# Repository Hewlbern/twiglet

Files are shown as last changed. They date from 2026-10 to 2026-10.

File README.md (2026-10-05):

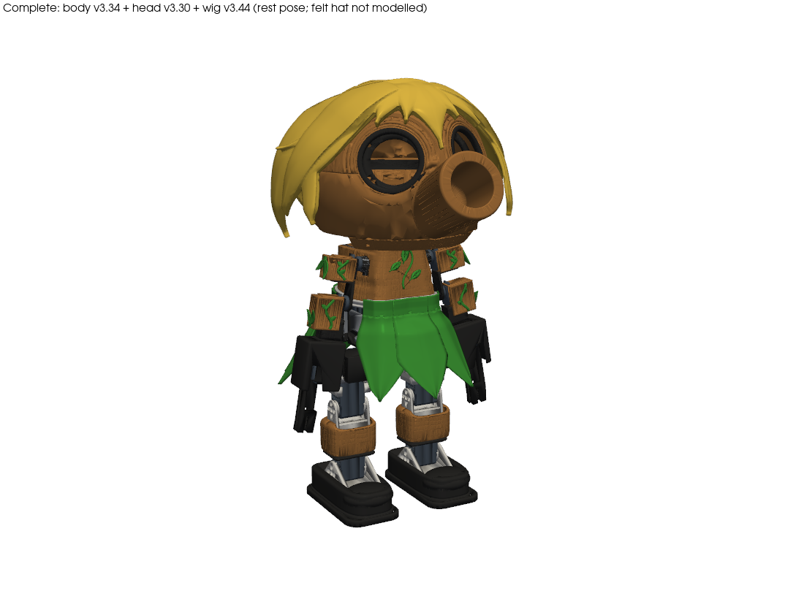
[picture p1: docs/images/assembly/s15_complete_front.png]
Twiglet: complete robot, rest pose (render)


# Twiglet

**Twiglet** is a ~50 cm, 19-DoF 3D-printed biped with a wooden-ball head, two round digital eyes, a printed hair piece under a felt hat, a leaf kilt and two small arms with grippers. It is **inspired by** [Open Duck Mini](https://github.com/apirrone/Open_Duck_Mini/tree/v2) (v2), and reuses some of its open-source parts (legs, neck, electronics) under Apache-2.0 — see [NOTICE](NOTICE).

[Hardware →](#hardware) · [BOM →](docs/BOM.md) · [Print →](docs/print_guide.md) · [Assemble →](docs/assembly_guide.md) · [Simulation →](experiments/README.md) · [Contribute →](CONTRIBUTING.md)

> **Status: simulation only.** Nothing has been printed or built yet, so every number below is from MuJoCo and mesh checks. Photos and videos of a real build are TODO.

| | | |
|:-:|:-:|:-:|
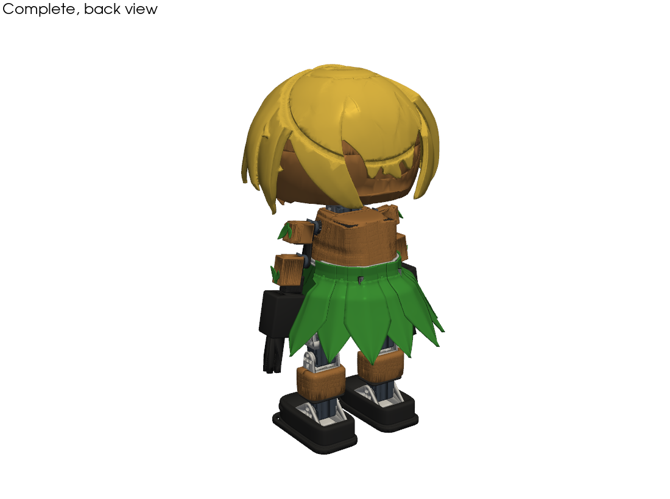
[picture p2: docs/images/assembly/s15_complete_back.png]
complete, back
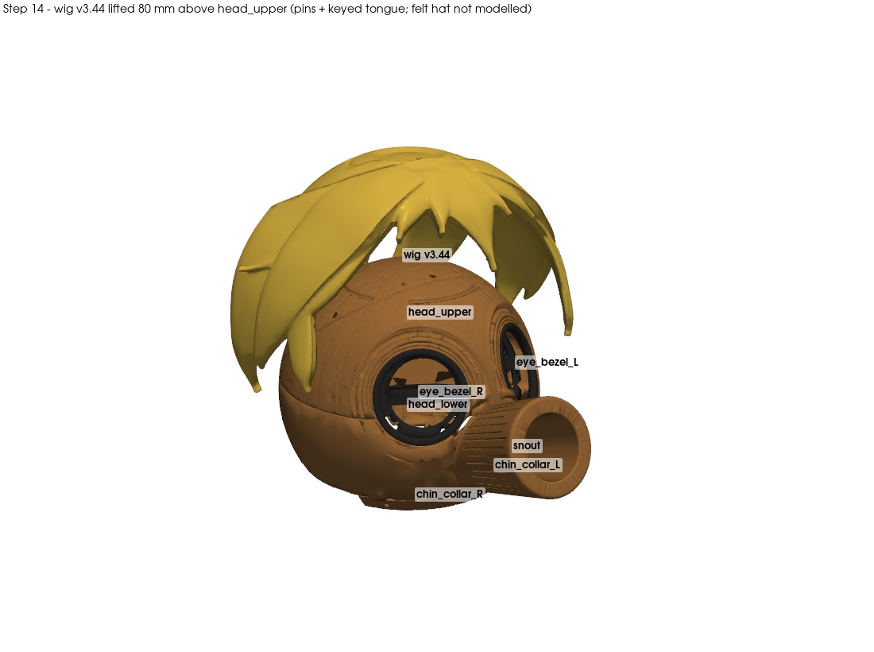
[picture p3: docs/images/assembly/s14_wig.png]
wig on the head
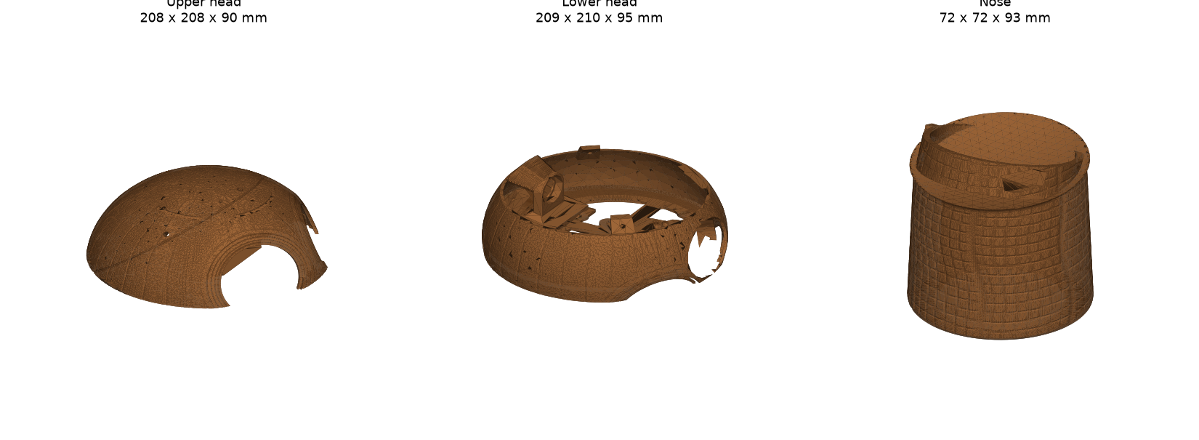
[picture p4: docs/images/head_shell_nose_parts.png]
head shells and nose
|  |  |  |
| **Complete, back view** | **Head + hair piece v3.44** | **Head shells and nose** |
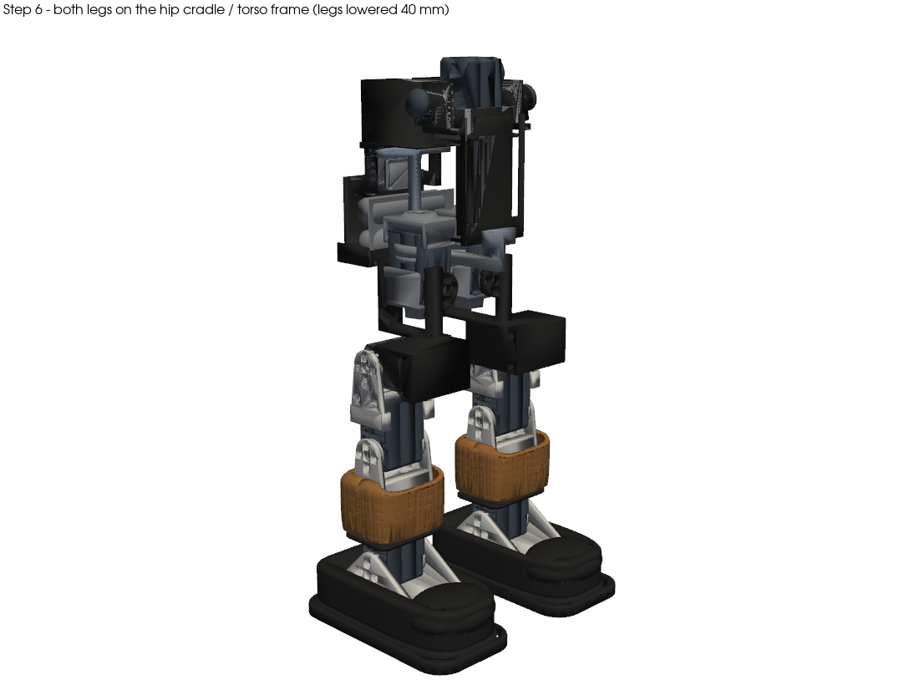
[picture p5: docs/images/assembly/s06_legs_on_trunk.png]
legs on the trunk
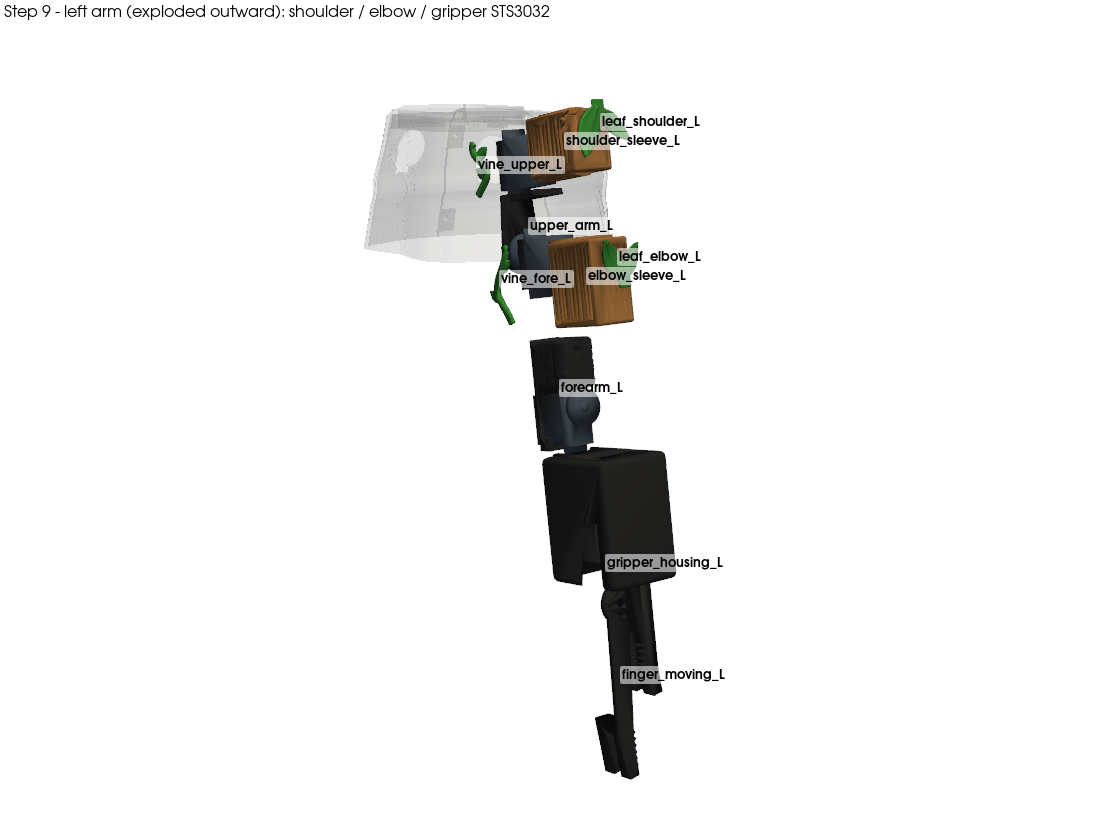
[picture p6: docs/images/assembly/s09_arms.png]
arms
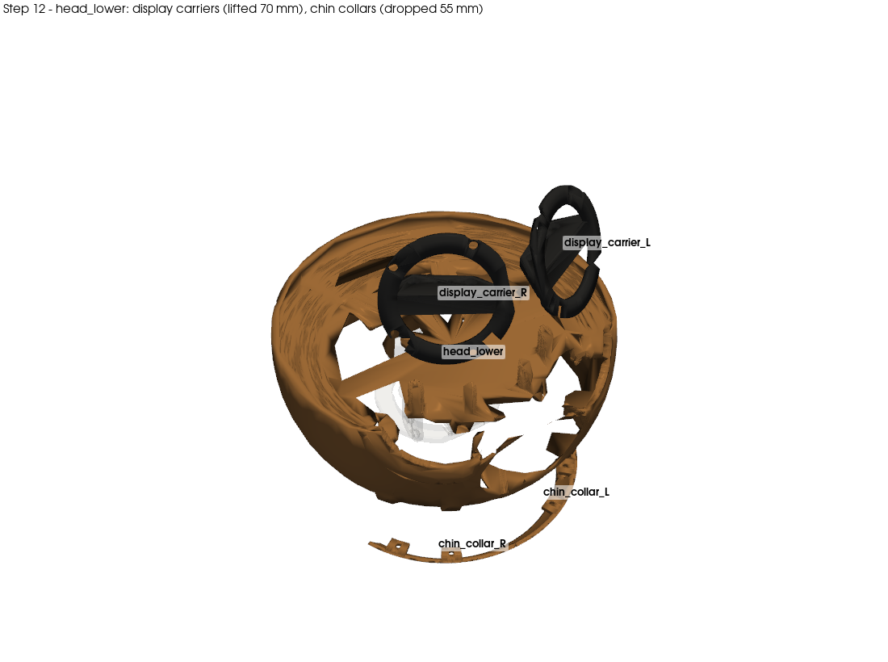
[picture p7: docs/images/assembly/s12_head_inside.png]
head inside
|  |  |  |
| **Legs on the trunk** | **3-DoF arms (STS3032)** | **Head inside: Pi, eyes, ballast** |

## Highlights

- **Head:** a new wood-textured ball head (v3.30) with a hollow nose and two 2.1" round touch LCDs as eyes (ESP32-S3; firmware in [`experiments/twiglet_eyes/`](experiments/twiglet_eyes/README.md)), using a 3-servo neck (Open Duck Mini v2-compatible).
- **Hair piece:** one printed piece (v3.44, 186 g at 4.5 % infill) that pins and keys onto the head; a felt hat goes over it.
- **Body:** a slim torso cone with a 10-petal leaf kilt, shin covers and boots (body v3.34, 50 STLs).
- **Arms:** two 3-DoF arms (shoulder, elbow, gripper) on Feetech STS3032 micro bus servos, powered from a 6 V buck regulator.
- **Simulation and checks:** MuJoCo model, open-loop gait parameters, standing, push and neck-load tests, plus collision and print-file checks on the real meshes. All of it runs from this repo.

## Hardware

| Category | Item | Specification |
|---|---|---|
| Body | Size | about 340 × 276 × 499 mm (feet to hair top, rest pose; hat not modelled) |
| Body | Mass (sim model) | 2.753 kg; head 0.814 kg including the 25 g ballast and the hair piece |
| Motion | Joints | 19: 10 legs + 3 neck (13 × Feetech STS3215), 6 arms (Feetech STS3032) |
| Computing | Main board | Raspberry Pi Zero 2W (as upstream) |
| Sensing | IMU | BNO055 (as upstream) |
| Interaction | Eyes | 2 × Waveshare ESP32-S3-Touch-LCD-2.1 (480 × 480 round), UART from the Pi |
| Power | Battery | 2S 18650 (2 cells) + 2S BMS; 5 V UBEC for logic and eyes; 6 V buck for the arm servos |
| Printing | Printer used for the checks | Bambu P1S (every part fits 256 × 256 × 256 mm), PLA / PETG / optional TPU |

Full parts list with links and prices: [docs/BOM.md](docs/BOM.md) (CSV: [docs/BOM.csv](docs/BOM.csv)). Several prices are still TODO.

## Simulation results

From [`experiments/`](experiments/README.md), model `experiments/twiglet_sim/models/twiglet_v3_v334_wig344.xml` (body v3.34 + head v3.30 + hair v3.44), re-run from this repo on 5 Oct 2026:

| check | result | pass criterion |
|---|---|---|
| standing margin (crouch 0.10) | 50.5 mm | no fall, > 30 mm |
| head + arm motion (e-margin) | 34.1 mm | ≥ 30 mm |
| neck-pitch static hold | 0.232 N·m = **2.11×** the STS3215 rating | ≥ 2× |
| main gait, 20 randomized trials | **19/20** at 0.206 m/s | ≥ 19/20 |
| main gait, 20 held-out seeds | 18/20 at 0.206 m/s | ≥ 18/20 |
| efficient gait, 20 randomized trials | **20/20** at 0.156 m/s | ≥ 19/20 |
| hair vs arms inside the soft limits | 0 / 0 / 0 (yaw 0 / −45 / +45) | 0 |
| 315-pose head range | 154/315 poses with any contact, 0 hair-only | ≤ ~154, 0 hair-only |
| eye coverage by the hair | 0 / 0 triangles | 0 |
| print files | watertight, 1 body, fit the P1S | all |

The gaits are 12-parameter open-loop/PD vectors ([BEST_WALK_PARAMS_v334r1.npy](BEST_WALK_PARAMS_v334r1.npy), [BEST_WALK_EFF_PARAMS_v333r1.npy](BEST_WALK_EFF_PARAMS_v333r1.npy); see `experiments/twiglet_sim/walk_search.py`), **not** ONNX RL policies like upstream's. Training a policy with [Open_Duck_Playground](https://github.com/apirrone/Open_Duck_Playground) is TODO.

## Where to find things

| Resource | Purpose |
|---|---|
| [docs/BOM.md](docs/BOM.md) | Parts list (upstream columns + our extra parts) |
| [docs/print_guide.md](docs/print_guide.md) | Which stock parts are still used, plus the print settings of every new part (some are **required**: the sims assume them) |
| [docs/assembly_guide.md](docs/assembly_guide.md) | 15-step build with rendered step images |
| [print/mods/Twiglet/](print/mods/Twiglet/README.md) | New STLs (print-oriented), Blender sources and build scripts |
| [mini_bdx/robots/twiglet_v334/](mini_bdx/robots/twiglet_v334/README.md) | MuJoCo model (MJCF + meshes) |
| [experiments/](experiments/README.md) | Every simulation and geometry check, how to run it, and the reference results |
| [docs/configure_motors.md](docs/configure_motors.md), [docs/sim2real.md](docs/sim2real.md), [docs/prepare_robot.md](docs/prepare_robot.md) | Servo IDs, sim-to-real notes, how the model was made |
| [docs/upstream/](docs/upstream/) | The upstream Open Duck Mini v2 docs, unchanged, for reference |

For the stock Open Duck Mini v2 parts use upstream's [Onshape CAD](https://cad.onshape.com/documents/64074dfcfa379b37d8a47762/w/3650ab4221e215a4f65eb7fe/e/0505c262d882183a25049d05) and [BOM](https://docs.google.com/spreadsheets/d/1gq4iWWHEJVgAA_eemkTEsshXqrYlFxXAPwO515KpCJc/edit?usp=sharing). The onboard runtime is upstream's [Open_Duck_Mini_Runtime](https://github.com/apirrone/Open_Duck_Mini_Runtime) (TODO: add the arm servos and the eye UART).

### Large files

Every file is under GitHub's 100 MB limit. Over 25 MB: `print/mods/Twiglet/source/blender/body_v334.blend` (59 MB). The head v3.30 `.blend` (194 MB) is not included; its rebuild scripts are in `print/mods/Twiglet/source/scripts/head_v3.30/`.

## Credits

Twiglet is **inspired by** **[Open Duck Mini](https://github.com/apirrone/Open_Duck_Mini)** (v2) by Antoine Pirrone ([apirrone](https://github.com/apirrone)) and the Open Duck Mini contributors (see [thanks.md](thanks.md)), sponsored by HuggingFace and Pollen Robotics. Some stock Open Duck Mini v2 parts, wiring diagrams and docs are reused here under the Apache License 2.0; [NOTICE](NOTICE) lists exactly which files are theirs, unmodified or modified. Thanks also to Rhoban for [BAM](https://github.com/Rhoban/bam), and to the [MuJoCo](https://github.com/google-deepmind/mujoco), [trimesh](https://github.com/mikedh/trimesh), [PyVista](https://github.com/pyvista/pyvista) and [Blender](https://www.blender.org/) projects.

This project is not affiliated with or endorsed by Pollen Robotics, HuggingFace or the Open Duck Mini project.

## License

Copyright 2026 Mike Holborn (DreamMachina).

The new material in this repository is licensed under the [Apache License 2.0](LICENSE). The Open Duck Mini v2 material stays under its own Apache-2.0 terms and copyright; see [NOTICE](NOTICE). Contributions are accepted under the same licence (see [CONTRIBUTING.md](CONTRIBUTING.md)).

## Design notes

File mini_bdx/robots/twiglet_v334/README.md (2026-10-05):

# twiglet_v334

This is the MuJoCo model of the Twiglet robot (body v3.34, head v3.30). Layout follows the Open Duck Mini v2 robot folder convention.

- `twiglet_v3.xml`: the MJCF, with 19 position actuators:
  - left/right `hip_yaw`, `hip_roll`, `hip_pitch`, `knee`, `ankle`
  - `head_pitch`, `head_yaw`, `head_roll`
  - `shoulder_L/R`, `elbow_L/R`, `gripper_L/R`
- `twiglet_v3_wig344.xml`: **the current robot**, the same model with the head inertial of the wig v3.44 (hair c14) head: 2.753 kg total, head 0.814 kg. It is a copy of `experiments/twiglet_sim/models/twiglet_v3_v334_wig344.xml` (made by `experiments/twiglet_sim/tools/make_v334_wig.py`).
- Total mass of `twiglet_v3.xml`: 2.753 kg.
- `meshes/`: 60 STL visual meshes. Contact is only the floor vs 4 boxes (trunk, feet, head); part-to-part clearance is checked on the print meshes in `experiments/twiglet_geom/`.
- `mass_v334.json`: the per-part mass deltas applied for v3.34.
- There is no URDF or onshape-to-robot `config.json`: the model was not made from Onshape (TODO, if the runtime/playground needs them).
- The 25 g head ballast is included in both. `twiglet_v3.xml` has the older v3.30-era fringe in the head mass; `twiglet_v3_wig344.xml` has wig v3.44.
- All the other versions (body v3.20–v3.34, infill sweeps, hair series) are in `experiments/twiglet_sim/models/`.

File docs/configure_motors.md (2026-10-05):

# Configure the motors

> This is based on the [Open Duck Mini v2 guide](https://github.com/apirrone/Open_Duck_Mini/blob/v2/docs/configure_motors.md). A verbatim copy is in [upstream/configure_motors.md](upstream/configure_motors.md).

> This sould be done independently on each motor *before* builiding the duck.
>
> During the process, the motor will move to its zero position. You can then install the horn while trying to align it the best you can. (Don't worry if it's not perfect, we will compensate for that later)

Clone and install (`pip install -e .`) the runtime repo on the `v2` branch : `https://github.com/apirrone/Open_Duck_Mini_Runtime`

Then for each motor, run the following command : 

```bash
python configure_motor.py --id <id>
```

The STS3215 IDs are upstream's, minus `neck_pitch`: Twiglet has had no neck-pitch servo since v3.5, so there are 13 STS3215s.

```python
{
    "left_hip_yaw": 20,
    "left_hip_roll": 21,
    "left_hip_pitch": 22,
    "left_knee": 23,
    "left_ankle": 24,
    # "neck_pitch": 30,  # not used in twiglet
    "head_pitch": 31,
    "head_yaw": 32,
    "head_roll": 33,
    "right_hip_yaw": 10,
    "right_hip_roll": 11,
    "right_hip_pitch": 12,
    "right_knee": 13,
    "right_ankle": 14,
}
```

The arm servos are 6× Feetech **STS3032**. They use the same STS TTL protocol and bus, but have to be powered from the **6 V** branch, not straight from the 2S pack.

```python
{
    # TODO: arm servo IDs not decided. The joint names below are the ones in the sim model.
    "shoulder_L": None,
    "elbow_L": None,
    "gripper_L": None,
    "shoulder_R": None,
    "elbow_R": None,
    "gripper_R": None,
}
```

- TODO: check that `configure_motor.py` works on the STS3032. The protocol and register map are said to be the same as the STS3215, but this has not been tested.

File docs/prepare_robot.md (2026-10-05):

# Prepare the robot (from design to MuJoCo)

> Upstream's version goes from the Onshape design to MuJoCo through onshape-to-robot: see [upstream/prepare_robot.md](upstream/prepare_robot.md). Twiglet has no Onshape document, so its model was made differently.

## Our model

- **Model file:** `mini_bdx/robots/twiglet_v334/twiglet_v3.xml`, with its meshes in `meshes/`.
  - 19 actuators: 10 legs, head_pitch/yaw/roll, and shoulder/elbow/gripper L/R.
  - 2.753 kg in total.
- **Current robot with wig v3.44:** `twiglet_v3_wig344.xml` (2.753 kg, head 0.814 kg), made by `experiments/twiglet_sim/tools/make_v334_wig.py`: the v3.34 model with the head inertial and head collision box of the hair c14 (v3.44) model `hair_c14_v344.xml`. That script runs from the repo (it only reads three files in `models/`). The 52 versions and variants are in `experiments/twiglet_sim/models/`.
- **How it was built:**
  - `experiments/twiglet_sim/tools/gen_mjcf_v3.py` built the v3 MJCF from the Open Duck Mini v2 kinematics, using the mass rules of our earlier body-v2 model plus new part kinds (STS3032 cases, light-print head, displays).
  - Each later version edited it. For example, `experiments/twiglet_sim/tools/mass_v334.py` adds the changed-part mass deltas (solid PLA, 1.24 g/cm3) to the bodies they ride on.
  - The mass bookkeeping is in `mini_bdx/robots/twiglet_v334/mass_v334.json`.
- **Reference only:** `gen_mjcf_v3.py`, `mass_v334.py` and `make_xml_variant.py` read caches and earlier versions from the original build workspace. They don't run on their own from this repo (TODO: make them self-contained).
- **Mass assumptions:** the head is modelled at 2 walls + 8 % infill (wig 4.5 % lightning), with the head shells, snout and chin collars in PETG at 1.27 g/cm3 and 25 g of rear ballast. Print exactly that, or the model no longer matches.
- **STS3032 arm actuators:**
  - ctrlrange is clipped to ±0.441 N·m (stall at 6 V).
  - The armature (0.004) is an estimate. The STS3032 has not been identified with BAM (TODO).

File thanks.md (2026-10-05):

Twiglet is inspired by Open Duck Mini by Antoine Pirrone ([apirrone](https://github.com/apirrone)): https://github.com/apirrone/Open_Duck_Mini. Thank you!

People involved in the original Open Duck Mini project, as listed in upstream's `thanks.md`:

- Mimir Reynisson
- Grégoire Passault
- Augustin Crampette
- Michel Aractingi
- Mankaran Singh
- Steve N'Guyen
- Pierre Rouanet
- Thomas Wolf

Also thanks to HuggingFace and Pollen Robotics for sponsoring Open Duck Mini, to Rhoban for [BAM](https://github.com/Rhoban/bam), and to Waveshare for the ESP32-S3-Touch-LCD-2.1 demo code the eye firmware is ported from.

Twiglet: DreamMachina / Mike Holborn.

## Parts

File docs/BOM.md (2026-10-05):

# BOM

> This uses the same columns and sections as the [upstream Open Duck Mini v2 BOM](https://docs.google.com/spreadsheets/d/1gq4iWWHEJVgAA_eemkTEsshXqrYlFxXAPwO515KpCJc/edit?usp=sharing).
> - Lines marked [upstream line] are upstream's, with their links and € prices. Only the amounts are changed for twiglet.
> - Prices we don't know are TODO.
> - CSV version: [BOM.csv](BOM.csv). Printed parts: see [print_guide.md](print_guide.md).

| section | Part | link | amount | unit price (€) | total price (€) | Estimated lowest price (€) | Comment |
|---|---|---|---|---|---|---|---|
| Power | 18650 cell | [link](https://www.nkon.nl/fr/molicel-inr18650-p30b-3000mah-30a.html) | 2 | 5 | 10 | 10 | Get the beefiest 18650 cells you can find. I have 3000mAh with 30A discharge [upstream line] |
|  | 18650 cell holder | [link](https://www.amazon.fr/CABLEPELADO-Support-pour-piles-MR18650/dp/B08YDTSML8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) | 1 | 4,99 | 4,99 | 4,99 | [upstream line] |
|  | 2S BMS | [link](https://shorturl.at/OEXM1) | 1 | 8,4 | 8,4 | 8,4 | [upstream line] |
|  | 5V regulator | [link](https://www.alibaba.com/product-detail/HENGE-4A-6A-8A-12A-UBEC_1601260325461.html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) | 1 | 4 | 4 | 4 | Also feeds the 2 eye boards (budget +0.5 A, not measured). TODO: check the headroom [upstream line] |
|  | Small power switch | [link](https://www.amazon.fr/dp/B0CH3JCQM5?psc=1&ref=ppx_yo2ov_dt_b_product_details) | 1 | 4,49 | 4,49 | 4,49 | Need only one [upstream line] |
|  | usb-c charger | [link](https://www.amazon.fr/dp/B0BWTK7SVN?psc=1&ref=ppx_yo2ov_dt_b_product_details) | 1 | 9,99 | 9,99 | 9,99 | need only one [upstream line] |
|  | 2.1mm barrel jack | [link](https://www.amazon.fr/AERZETIX-connecteur-Adaptateur-dalimentation-souder/dp/B07VQ6VFDN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) | 2 | 1 | 2 | 2 | Need only two [upstream line] |
|  | XT15? XT30 ? | [link](https://www.amazon.fr/RUNCCI-connecteur-XT30Connecteurs-Batterie-connecteurs/dp/B07PC1YKVW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) | 1 | 8 | 8 | 0.5 | You only need one pair (male/female) but hard to buy just one. Estimated lowest price is the price of 1, unit price is the price of a bundle [upstream line] |
|  | 6V buck regulator for the arm branch (e.g. Pololu D36V50F6, 6V 5.5A) |  | 1 | TODO | TODO | TODO | Twiglet: the STS3032 max is 7.4V and a full 2S is 8.4V. TODO: link and price |
| Servos, control and sensors | IMU (BNO055) | [link](https://www.amazon.fr/gp/product/B017PEIGIG/ref=ox_sc_act_title_2?smid=AZ997SEAZ4L8C&psc=1) | 1 | 40 | 40 | 1 | Need to find a cheaper alternative. Saw ~1$ ones on ali, but would have to try them https://www.alibaba.com/product-detail/BNO055-9DOF-9-axis-Absolute-Orientation_1601030871509.html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 [upstream line] |
|  | Raspberry pi zero 2w | [link](https://t.ly/M21v4) | 1 | 26,08 | 26,08 | 26,08 | [upstream line] |
|  | SD card | [link](https://www.amazon.fr/SanDisk-M%C3%A9moire-microSDHC-Adaptateur-homologu%C3%A9e/dp/B08GY9NYRM/257-3914705-5327951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) | 1 | 10 | 10 | 10 | TODO can find cheaper [upstream line] |
|  | Servo control board | [link](https://www.waveshare.com/bus-servo-adapter-a.htm) | 1 | 5 | 5 | 5 | [upstream line] |
|  | Feetech 7.4v STS 3215 | [link](https://www.alibaba.com/product-detail/Robot-Servo-STS3215-7-4V-19kg_1600052037414.html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) | 13 | 14 | 182 | TODO | 13, not 14: 10 legs + head pitch/yaw/roll (the neck-pitch servo was removed in v3.5). Be sure to buy the 7.4v ones [upstream line] |
|  | Feetech STS3032 (C001) micro bus servo | [link](https://shop.babsco.com/feetech-sts3032-4-5kg-compact-smart-servo-c001) | 6 | TODO (US$32.99) | TODO (US$197.94) | TODO | Twiglet arms: shoulder, elbow and gripper per side. Prices seen: US$32.99 BABSCO; EUR 37.20 Eckstein |
|  | Feet contact switches (SS-10) | [link](https://fr.aliexpress.com/item/1005006164610609.html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) | TODO | 1 | TODO | TODO | TODO: fitted or not? They are not modelled in the sim [upstream line] |
|  | 9g servos | [link](https://www.amazon.fr/Miuzei-H%C3%A9licopt%C3%A8re-V%C3%A9hicules-Contr%C3%B4le-Mod%C3%A9lisme/dp/B0BBR4D8SZ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) | 0 | 3,33 | 0 | TODO | Not used: the antennas are omitted [upstream line] |
|  | Waveshare ESP32-S3-Touch-LCD-2.1 (flat, SKU 28169) | [link](https://www.waveshare.com/esp32-s3-touch-lcd-2.1.htm?sku=28169) | 2 | TODO (US$32.99) | TODO (US$66) | TODO | Twiglet digital eyes. Do NOT buy the 2.1B (curved glass). In AU: about AU$126 for 2 (Zaitronics) |
|  | SH1.0 12-pin cable, ~150 mm |  | 2 | TODO | TODO (~AU$5) | TODO | For the eyes. Check the display box first |
|  | 4-pin inline connector + ~30 cm of 26 AWG wire |  | 1 | TODO | TODO (~AU$3) | TODO | Eyes to Pi |
| MISC | 3D printing M3 inserts | [link](https://www.amazon.fr/dp/B09ZPF48VK?psc=1&ref=ppx_yo2ov_dt_b_product_details) | 1 | 5,99 | 5,99 | 5,99 | Twiglet extras: 4x M3x5x4 (chin collars), 4x M3x4x5 (display carriers) and 4 (head halves). Total count TODO [upstream line] |
|  | M3x8 socket-head screws |  | 8 | TODO | TODO | TODO | 4 for the chin collars + 4 for the display carriers |
|  | M3 screws, head-half joint |  | 4 | TODO | TODO | TODO | Length TODO |
|  | M3 screws (other) |  | TODO | TODO | TODO | TODO | Upstream says "X m3 screws (TODO)". The Twiglet body/arm fasteners are TODO too |
|  | M2x5 pan/button-head screws |  | 8 | TODO | TODO (<AU$3) | TODO | Displays to carriers |
|  | M2 screws, arms |  | TODO | TODO | TODO | TODO | upper_arm to the sleeve and servo ears (from the v3.1/v3.8 notes). Count and length TODO |
|  | Standard PLA |  | 1 | 20 | 20 | 0 | Twiglet colours: black, wood-brown, green, yellow/blond. Amount TODO [upstream line] |
|  | PETG, wood-brown |  | TODO | TODO | TODO | TODO | Head shells, snout and chin collars |
|  | TPU |  | 1 | 0 | 0 | 0 | (for the feet, negligeable cost). Optional TPU 95A for the kilt petals, leaves and boots [upstream line] |
|  | Cable sheath | [link](https://www.amazon.fr/gp/product/B07PGMKC3T/ref=ox_sc_act_title_4?smid=A33G7CY43FZYTX&psc=1) | 1 | 9 | 9 | 9 | [upstream line] |
|  | 15cm micro usb to usb-c cable | [link](https://www.amazon.fr/AmazonBasics-C%C3%A2ble-USB-C-vers-Micro/dp/B01LONQ7R6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) | 1 | 7 | 7 | 7 | [upstream line] |
|  | 50cm micro usb to usb c cable | [link](https://www.amazon.fr/gp/product/B0BFWSP4PP/ref=ox_sc_act_title_2?smid=A1VSNBJQRMXLRM&psc=1) | 1 | 6 | 6 | 6 | [upstream line] |
|  | Bearing | [link](https://www.amazon.fr/dp/B0CXXSVFTV?ref=ppx_yo2ov_dt_b_fed_asin_title) | 3 | 3,5 | 10,5 | 10,5 | The head roll bearing is 20x32x7 (in head_lower). TODO: confirm whether the other 2 (trunk) are still needed [upstream line] |
|  | Steel ballast, 25 g (e.g. 5x M8 hex nuts) |  | 1 | TODO | TODO | TODO | Required. Epoxied inside the back of head_lower; must weigh 23-27 g |
|  | 3 mm steel rod (or PLA filament), cut to 12 mm |  | 4 | TODO | TODO | TODO | Wig pins |
|  | 2-part epoxy + medium CA |  | 1 | TODO | TODO | TODO | For the wig, snout, ballast and leaves |
|  | Loctite 243 |  | 1 | TODO | TODO | TODO | From the upstream assembly guide |
|  | Felt hat (fabric) |  | 1 | TODO | TODO | TODO | Not printed |
|  | 0.3-0.5 mm black foam tape ring (optional) |  | 2 | TODO | TODO | TODO | Between the bezel and the glass |
| "Expression package" | (upstream projector, speaker, LEDs, microphone, eye diffusers, amplifier, camera) | [link](https://docs.google.com/spreadsheets/d/1gq4iWWHEJVgAA_eemkTEsshXqrYlFxXAPwO515KpCJc/edit?usp=sharing) | 0 |  |  |  | Replaced by the digital eyes. TODO: decide on the speaker, amplifier and camera |
|  |  |  |  | Total | TODO | TODO | Not totalled: several prices are TODO |

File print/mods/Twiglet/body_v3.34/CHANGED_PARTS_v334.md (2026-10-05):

# Twiglet body v3.34: changed-part list (compared with v3.33)

Every part not listed is the same file as in v3.33 (the v333_ arm files are copied unchanged from the v3.33 zip; the v3.34 rebuild gave identical volumes and extents).

| Part | v3.34 file | Replaces | What changed | Solid vol v3.33 -> v3.34 |
|---|---|---|---|---|
| gripper_housing_L/R | v334_gripper_housing_L/R.stl | v333_gripper_housing_L/R | FEETECH box enlarged to 36.4 x 47.3 x 57.0 mm (was 29.4 x 47.3 x 43.0): +14 mm along the forearm (down), +3.5 mm depth per side. Still a hollow 1.6 mm shell with an open bottom; servo seat, prongs and finger unchanged (seat overlap 214.6 mm3 = rev C). | 37.01 -> 41.72 cm3 |
| kilt_petal_00..02 (front) | v334_kilt_petal_00..02.stl | v333_kilt_petal_00..02 | Flare radius 98 -> 118 mm about the kilt axis; hem height unchanged (-66); side edges clamp at |y| 65.5 (arm corridor). Pointed tips kept. | 8.28/8.50/8.28 -> 9.07/9.78/9.07 cm3 |
| kilt_petal_03..09 (sides/back) | v334_kilt_petal_03..09.stl | v333_kilt_petal_03..09 | Flare radius 102 -> 122 mm, hem 6 mm lower (-72); the side-back petals now reach |y| 124.6 behind the arms. | 6.26-7.89 -> 7.64-9.30 cm3 |

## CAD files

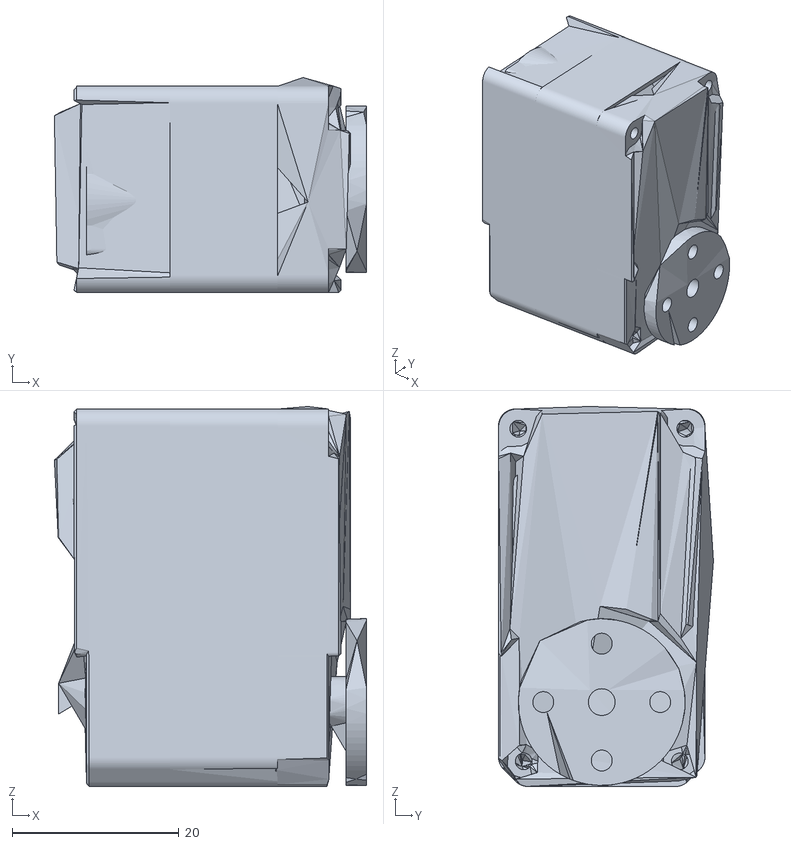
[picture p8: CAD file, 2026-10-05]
mini_bdx/robots/twiglet_v334/meshes/v3_hip_roll_assembly_2_servo.stl
37.4 x 25.7 x 45.5

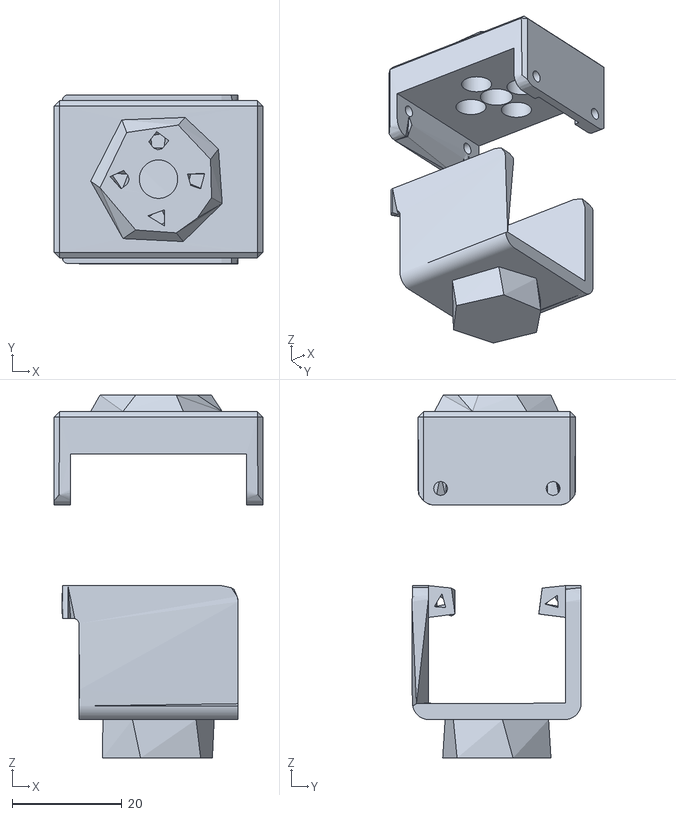
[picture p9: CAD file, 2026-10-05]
mini_bdx/robots/twiglet_v334/meshes/v3_hip_roll_assembly_black.stl
38.0 x 30.9 x 66.1

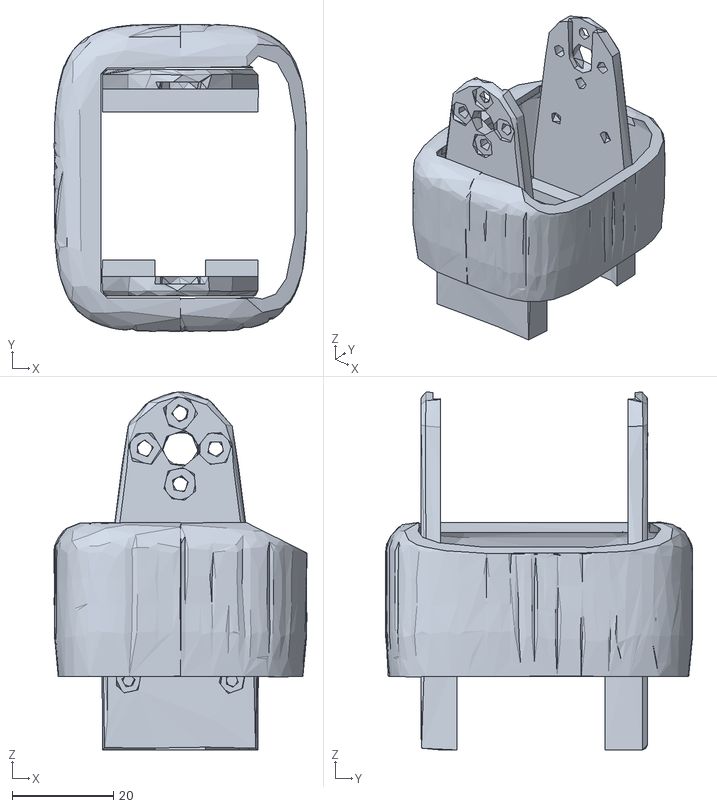
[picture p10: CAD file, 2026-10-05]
mini_bdx/robots/twiglet_v334/meshes/v3_knee_and_ankle_assembly_2_wood.stl
50.0 x 60.8 x 70.8

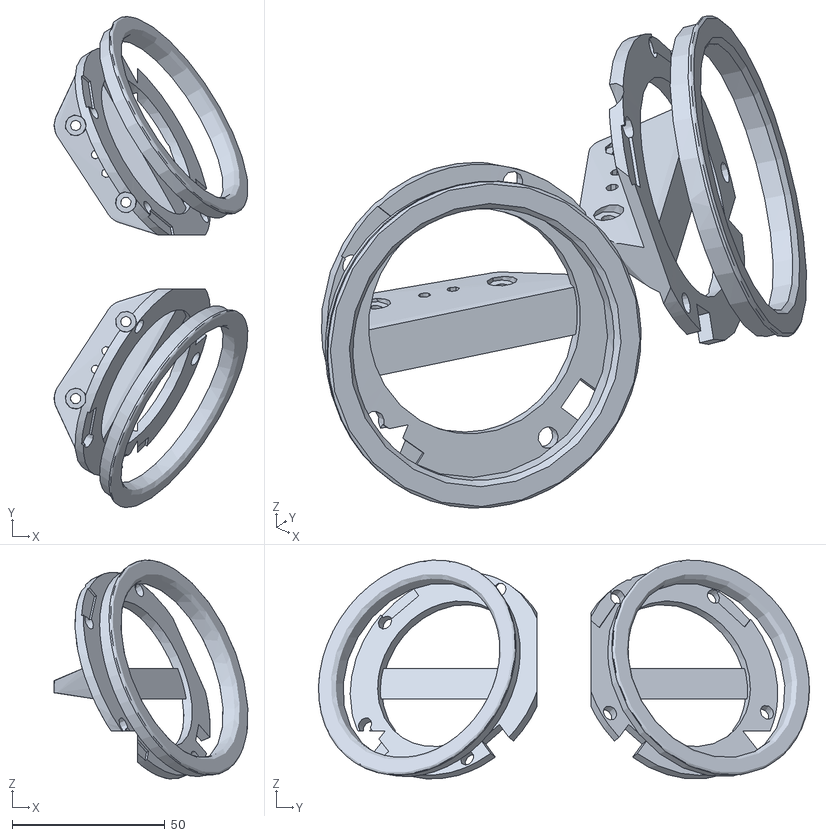
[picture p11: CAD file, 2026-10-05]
mini_bdx/robots/twiglet_v334/meshes/v3_head_assembly_dark.stl
63.4 x 160.7 x 71.6

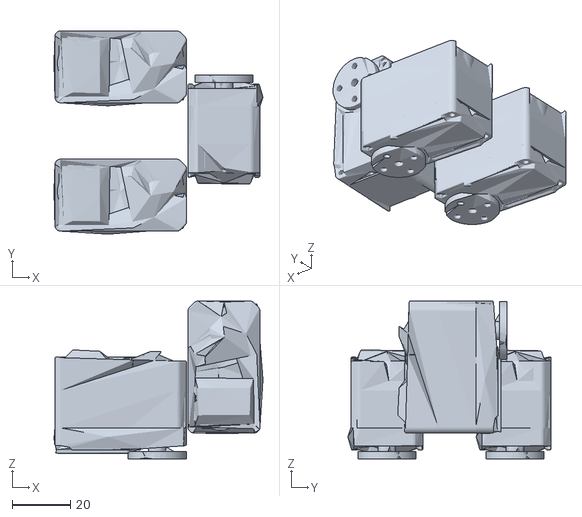
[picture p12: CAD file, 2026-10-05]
mini_bdx/robots/twiglet_v334/meshes/v3_trunk_assembly_servo.stl
71.7 x 69.7 x 54.2

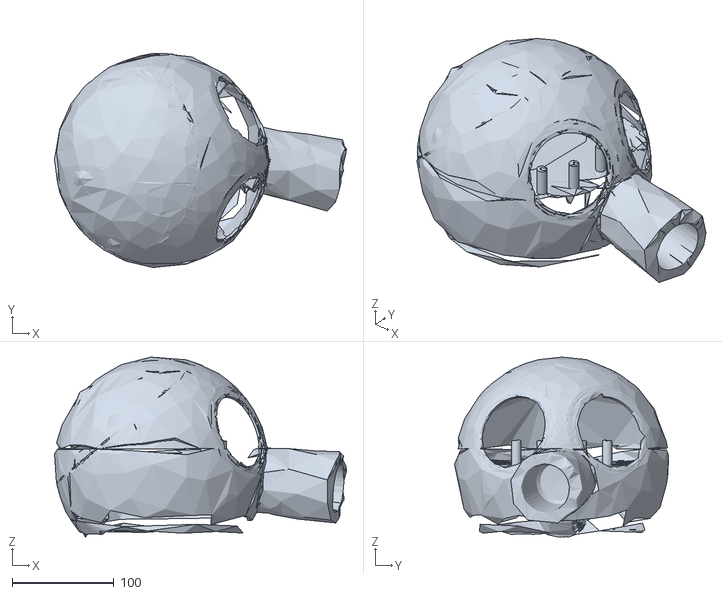
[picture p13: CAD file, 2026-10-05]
mini_bdx/robots/twiglet_v334/meshes/v3_head_assembly_wood.stl
287.3 x 210.6 x 176.9

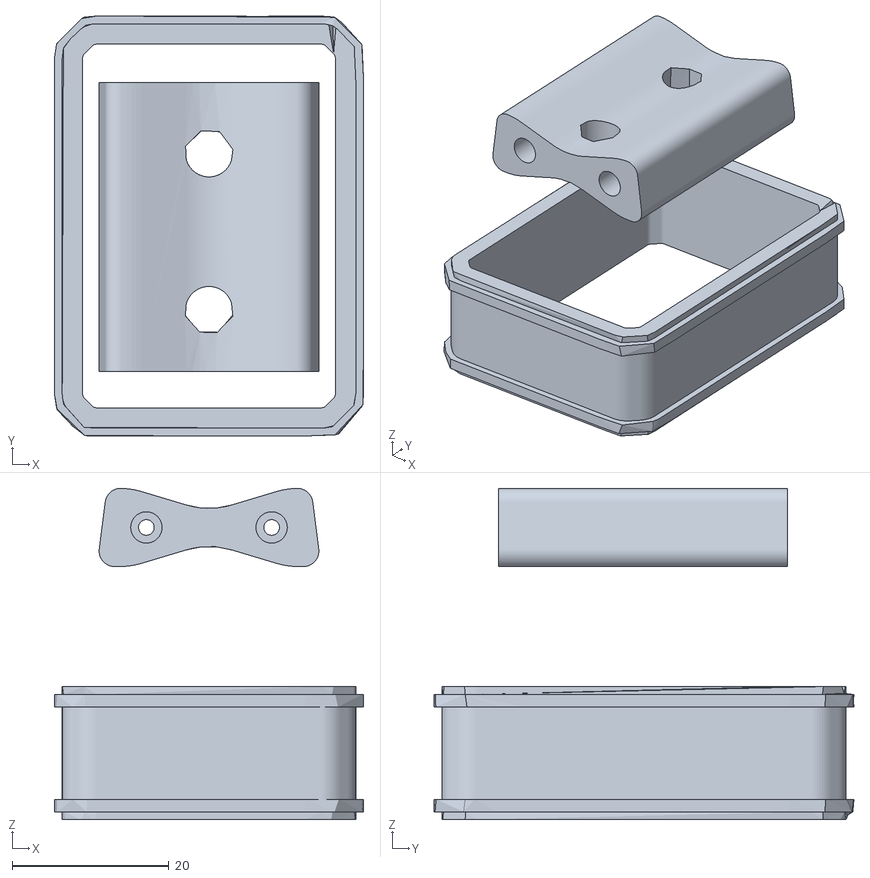
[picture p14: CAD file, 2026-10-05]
mini_bdx/robots/twiglet_v334/meshes/v3_knee_and_ankle_assembly_4_black.stl
39.5 x 53.6 x 42.3

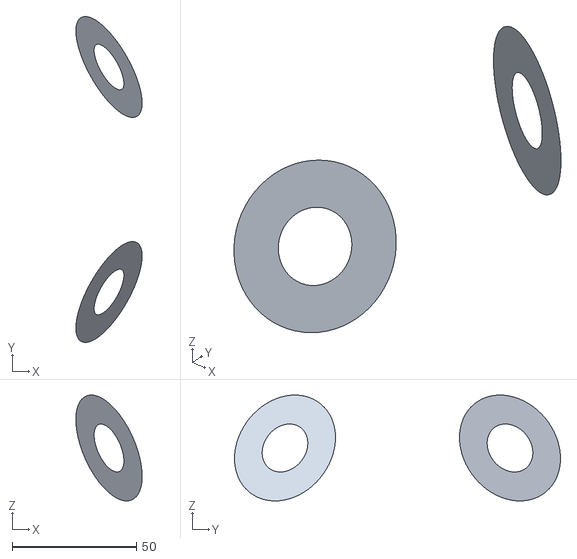
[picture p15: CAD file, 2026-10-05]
mini_bdx/robots/twiglet_v334/meshes/v3_head_assembly_eyeorange.stl
26.7 x 131.3 x 42.7

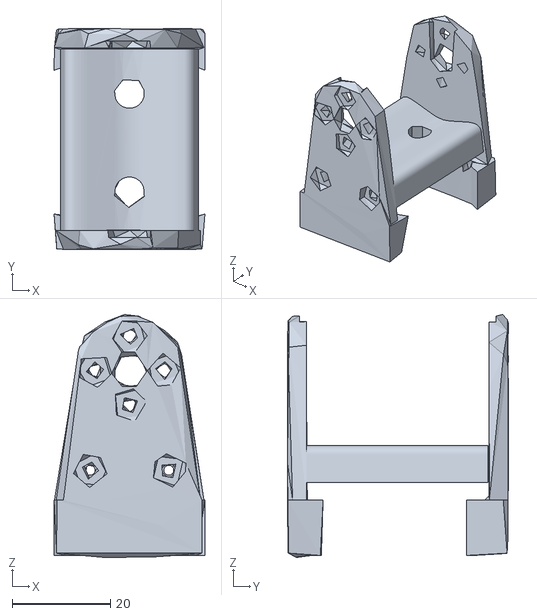
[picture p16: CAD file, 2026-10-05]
mini_bdx/robots/twiglet_v334/meshes/v3_knee_and_ankle_assembly_3_wood.stl
30.7 x 45.0 x 49.4

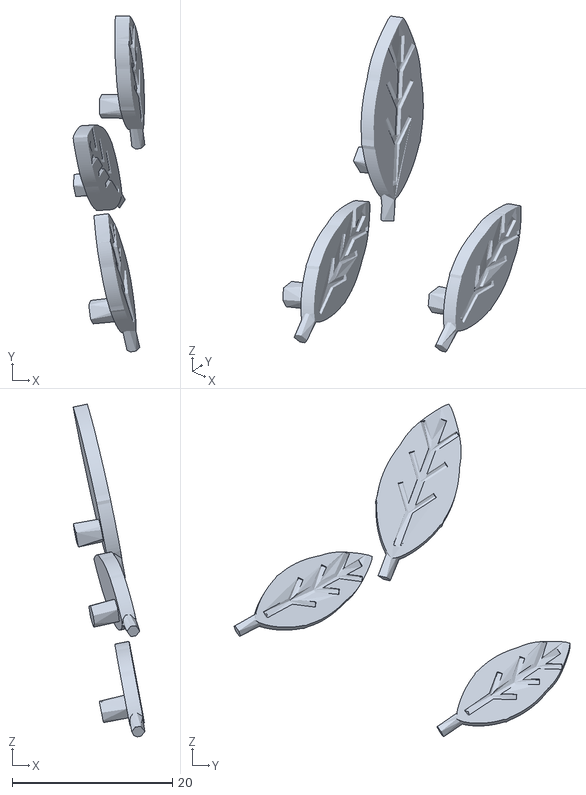
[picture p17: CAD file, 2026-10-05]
mini_bdx/robots/twiglet_v334/meshes/v3_trunk_assembly_leaf.stl
8.96 x 42.0 x 41.6

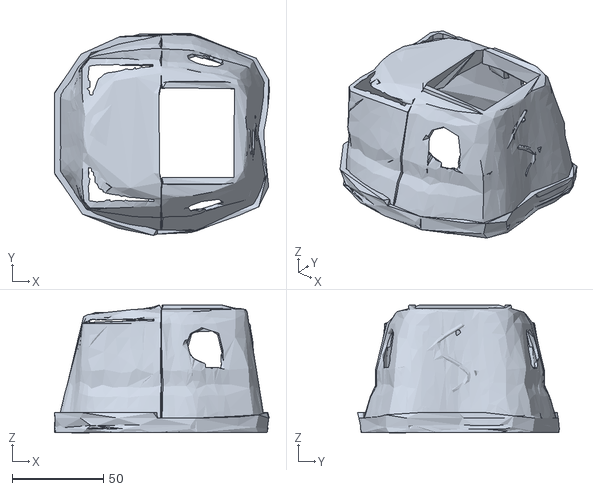
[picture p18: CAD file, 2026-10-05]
mini_bdx/robots/twiglet_v334/meshes/v3_trunk_assembly_wood.stl
118.0 x 110.8 x 70.1

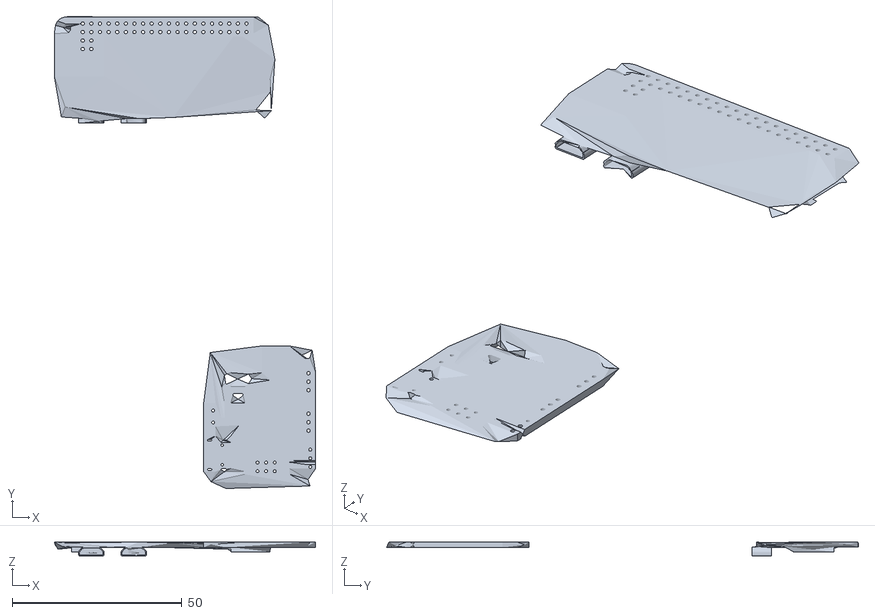
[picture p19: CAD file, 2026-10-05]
mini_bdx/robots/twiglet_v334/meshes/v3_head_assembly_grey.stl
77.0 x 139.1 x 4.10

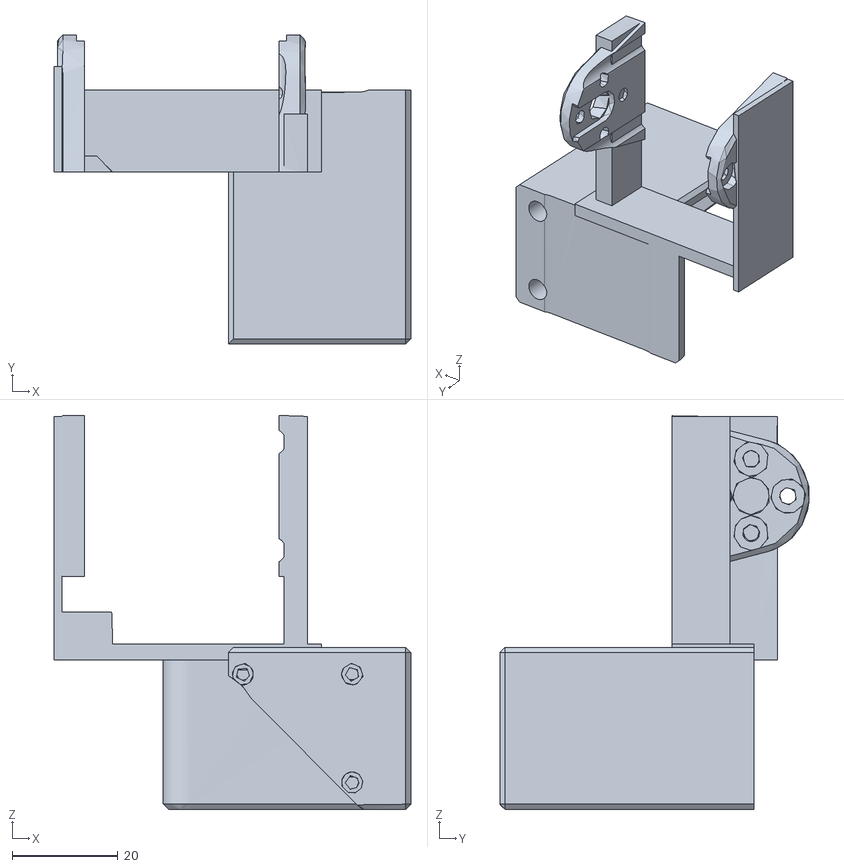
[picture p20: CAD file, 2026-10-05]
mini_bdx/robots/twiglet_v334/meshes/v3_right_roll_to_pitch_assembly_black.stl
67.5 x 58.6 x 74.6

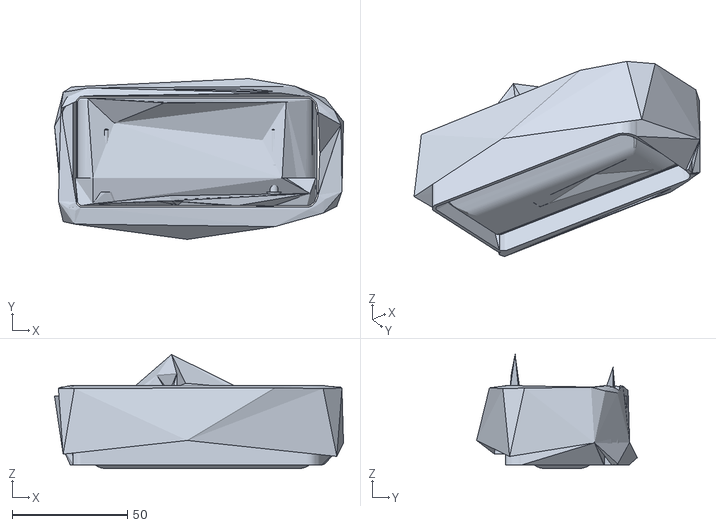
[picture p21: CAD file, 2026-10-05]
mini_bdx/robots/twiglet_v334/meshes/v3_foot_assembly_2_black.stl
125.6 x 69.9 x 49.6

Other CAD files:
mini_bdx/robots/twiglet_v334/meshes/v3_knee_and_ankle_assembly_2_black.stl
mini_bdx/robots/twiglet_v334/meshes/v3_trunk_assembly_s32.stl
mini_bdx/robots/twiglet_v334/meshes/v3_trunk_assembly_kilt.stl
mini_bdx/robots/twiglet_v334/meshes/v3_knee_and_ankle_assembly_4_servo.stl
mini_bdx/robots/twiglet_v334/meshes/v3_finger_L_black.stl
mini_bdx/robots/twiglet_v334/meshes/v3_finger_L_s32.stl
mini_bdx/robots/twiglet_v334/meshes/v3_finger_R_black.stl
mini_bdx/robots/twiglet_v334/meshes/v3_finger_R_s32.stl
mini_bdx/robots/twiglet_v334/meshes/v3_foot_assembly_black.stl
mini_bdx/robots/twiglet_v334/meshes/v3_fore_arm_L_black.stl
mini_bdx/robots/twiglet_v334/meshes/v3_fore_arm_L_leaf.stl
mini_bdx/robots/twiglet_v334/meshes/v3_fore_arm_L_s32.stl
mini_bdx/robots/twiglet_v334/meshes/v3_fore_arm_L_wood.stl
mini_bdx/robots/twiglet_v334/meshes/v3_fore_arm_R_black.stl
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

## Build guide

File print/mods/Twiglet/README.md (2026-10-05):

# Twiglet mod

Printable parts for Twiglet (inspired by Open Duck Mini): a wooden-ball head with digital eyes, a one-piece wig under a felt hat, a slim torso cone with a leaf kilt, and two 3-DOF STS3032 arms with grippers.

Upstream mods ship `.step` and `.3mf` files. This mod was made in Blender, so it ships STLs (already in print orientation) plus `.blend` and Python sources instead. TODO: export `.3mf` plates.

<table>
  <tr>
    <td> </td>
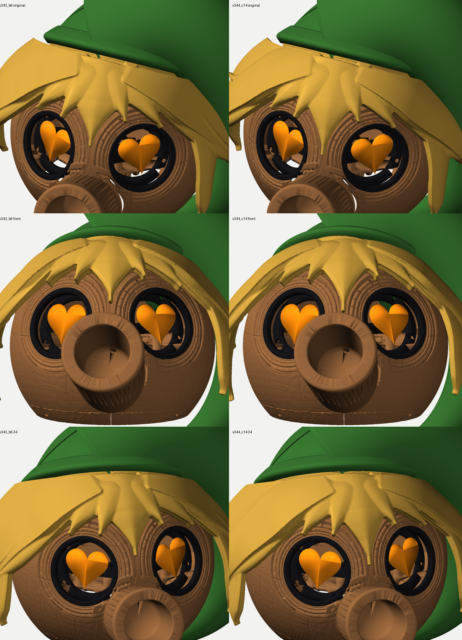
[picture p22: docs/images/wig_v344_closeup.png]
    <td> </td>
   </tr> 
</table>

| Folder | Version | Contents |
|---|---|---|
| `body_v3.34/` | body v3.34 (final) | 50 STLs: torso frame and shells, hip cradle and brackets, thigh sheets and spacers, shin covers, boots and cuffs, arms and grippers, leaves and vines, kilt band and 10 petals. Also `print_sheet_body_v334.md`, `CHANGED_PARTS_v334.md`, `README_v334.md` and `metrics_v334.json` |
| `head_v3.30/` | head v3.30 (final) | 10 STLs: head_upper/lower, snout, chin collars, eye bezels, display carriers, `head_yaw_to_roll` (a neck part; print it instead of the stock one). Also `print_note_head_v330.md`, `README_v330.md` and the print/mesh reports. The old v3.30 wig is left out on purpose. |
| `wig_v3.44/` | hair v3.44 (c14, final) | `FINAL_WIG.stl` (print-oriented; yellow PLA, 4.5 % lightning, 186.2 g), `FINAL_WIG_model_frame.stl` (same mesh in the head model frame, for the sims and checks; do not print this one), `NOTES_wig_v344.md`, `final_export.json`. The v3.40 notes are in `experiments/history/hair-v3.40/`. |
| `source/blender/` | | `body_v334.blend` (59 MB, flagged > 25 MB) and `hair_v344.blend` (3.7 MB, object `FINAL_WIG_v344_c14`). `head_v330.blend` (194 MB) is **not included** because it is over GitHub's 100 MB limit (TODO). |
| `source/scripts/` | | Blender/Python build scripts: `body_v3.34/`, `head_v3.30/` (with `README_blender.md`) and `wig_v3.44/` (with `variants/c14.*`, the edit set for the final wig). They are provenance: some need the original build workspace (`$WORK`) and the base `base_wig_v330.blend`, which is not included. |

Print settings: [docs/print_guide.md](../../../docs/print_guide.md). Assembly: [docs/assembly_guide.md](../../../docs/assembly_guide.md). BOM: [docs/BOM.md](../../../docs/BOM.md).

Stock Open Duck Mini v2 parts that are still used: feet, `roll_motor_top/bottom`, knee-to-ankle sheets, `leg_spacer`, `head_pitch_to_yaw` and `head_roll_mount` (in `print/`).

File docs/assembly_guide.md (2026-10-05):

# Assembly guide

> This is the Twiglet assembly guide. It follows the structure of the [Open Duck Mini v2 assembly guide](https://github.com/apirrone/Open_Duck_Mini/blob/v2/docs/assembly_guide.md) by apirrone and the Open Duck Mini contributors. The steps marked **(upstream)** are theirs, unchanged, and link to the original with its photos. A verbatim copy is in [upstream/assembly_guide.md](upstream/assembly_guide.md). The steps marked **(Twiglet)** are ours.
>
> **Nothing has been built yet.** Our steps come from the design notes (body v3.1–v3.34, head v2 / v3 digital eyes / v3.30, hair v3.44) and have not been checked on a real robot. Anything we don't know is marked **TODO**. Nothing here is guessed: if a screw length or a fixing isn't in our records, it says TODO.

> Before assembling the duck, you should first [configure your motors](./configure_motors.md)

**About the images.** The step images in `images/assembly/` are rendered from the v3.34 + wig v3.44 rest-pose measurement scene and from the print STLs, by [`experiments/twiglet_geom/render_assembly.py`](../experiments/twiglet_geom/render_assembly.py) (`python render_assembly.py`, about 15 s). Re-run it after any part change.
- In the exploded views, the parts of the step are in colour and the parts already fitted are a faint grey ghost.
- The scene is a simulation scene, not CAD. Servos, horns and bearings are simple dark-grey stand-ins. Anything labelled "(sim)" is a lumped mass (boards, battery, screws), **not** a printed part.
- The "parts" images show every print file of the step in its print orientation, labelled with its quantity. "2?" means the quantity is still a TODO.

<table>
  <tr>
    <td> s15_complete_front</td>
    <td> s15_complete_back</td>
   </tr> 
</table>

## Build order

| Step | What | Images |
|---|---|---|
| 0 | Print, configure the motors, fit the heat-set inserts | – |
| 1 | Feet + boots | `s01_feet`, `s01_feet_parts` |
| 2 | Shins + shin covers | `s02_shins`, `s02_shins_parts` |
| 3 | Thighs | `s03_thighs`, `s03_thighs_parts` |
| 4 | Hips | `s04_hips`, `s04_hips_parts` |
| 5 | Trunk: torso frame (battery tray) + hip cradle | `s05_trunk`, `s05_trunk_parts` |
| 6 | Legs on the trunk | `s06_legs_on_trunk` |
| 7 | Electronics: servo board, IMU, battery, 6 V arm branch, wiring | `s07_electronics` |
| 8 | Torso shells + chest leaves | `s08_torso_shells` |
| 9 | Arms + grippers | `s09_arms`, `s09_arms_parts` |
| 10 | Kilt band + petals | `s10_kilt`, `s10_kilt_parts` |
| 11 | Neck + head mechanism | `s11_neck`, `s11_neck_parts` |
| 12 | Head v3.30 inside: inserts, bearing, ballast, Pi, eyes, chin collars | `s12_head_inside`, `s12_head_parts` |
| 13 | Close the head: bezels, head_upper, snout | `s13_head_close` |
| 14 | Wig v3.44 + felt hat | `s14_wig`, `s14_wig_parts` |
| 15 | Final checks | `s15_complete_front/back` |

## Parts to step

Every print file and the step that uses it. Print settings are in [print_guide.md](print_guide.md) and the per-pack print sheets.

| Step | File | Qty | Colour | Where |
|---|---|---|---|---|
| 1 | `foot_top.stl` | 2 | stock | [print/](../print) (stock ODM v2) |
| 1 | `foot_side.stl` | 2 | stock | print/ |
| 1 | `foot_bottom_pla.stl` | 2 | stock | print/ |
| 1 | `foot_bottom_tpu.stl` | 2 | TPU | print/ |
| 1 | `v332_boot_L.stl`, `v332_boot_R.stl` | 1 + 1 | black (PETG/TPU 95A, PLA ok) | [body_v3.34](../print/mods/Twiglet/body_v3.34) |
| 1 | `v39_boot_cuff.stl` | 2 | black | body_v3.34 |
| 2 | `knee_to_ankle_left_sheet.stl` | TODO (the scene has 1 per shin, so 2) | stock | print/ |
| 2 | `knee_to_ankle_right_sheet.stl` | TODO (1 per shin in the scene, so 2) | stock | print/ |
| 2 | `leg_spacer.stl` | TODO (1 per shin in the scene, so 2) | stock | print/ |
| 2 | `v332_shin_cover_front_L/R.stl`, `v332_shin_cover_back_L/R.stl` | 4 | wood-brown | body_v3.34 |
| 3 | `v39_thigh_sheet_a.stl` | 2 | black | body_v3.34 |
| 3 | `v331_thigh_sheet_b.stl` | 2 | black | body_v3.34 |
| 3 | `v39_thigh_spacer.stl` | 2 | black | body_v3.34 |
| 4 | `roll_motor_top.stl` | 2 | stock | print/ |
| 4 | `roll_motor_bottom.stl` | 2 | stock | print/ |
| 4 | `v39_hip_bracket_L.stl`, `v39_hip_bracket_R.stl` | 1 + 1 | black PETG/PLA+ (load path) | body_v3.34 |
| 5 | `v331_torso_frame.stl` | 1 | any (hidden), PLA+/PETG | body_v3.34 |
| 5 | `v39_hip_cradle.stl` | 1 | any (hidden) | body_v3.34 |
| 8 | `v331_torso_shell_front.stl`, `v331_torso_shell_back.stl` | 1 + 1 | wood-brown | body_v3.34 |
| 8 | `v332_chest_vine.stl` | 1 | green | body_v3.34 |
| 8 | `v39_leaf_M.stl` (chest) | 1 | green | body_v3.34 |
| 8 | `v39_leaf_S.stl` (vine) | 2 | green | body_v3.34 |
| 9 | `v333_shoulder_sleeve_L/R.stl` | 1 + 1 | wood-brown | body_v3.34 |
| 9 | `v39_upper_arm_L/R.stl` | 1 + 1 | black | body_v3.34 |
| 9 | `v333_elbow_sleeve_L/R.stl` | 1 + 1 | wood-brown | body_v3.34 |
| 9 | `v39_forearm_L/R.stl` | 1 + 1 | black | body_v3.34 |
| 9 | `v334_gripper_housing_L/R.stl` | 1 + 1 | black | body_v3.34 |
| 9 | `v333_finger_moving_L/R.stl` | 1 + 1 | black | body_v3.34 |
| 9 | `v333_leaf_shoulder_L/R.stl`, `v333_leaf_elbow_L/R.stl` | 4 | green | body_v3.34 |
| 9 | `v333_vine_upper_L/R.stl`, `v333_vine_fore_L/R.stl` | 4 | green | body_v3.34 |
| 10 | `v331_kilt_band.stl` | 1 | green | body_v3.34 |
| 10 | `v334_kilt_petal_00.stl` … `v334_kilt_petal_09.stl` | 10 (1 each) | green PLA (or TPU 95A) | body_v3.34 |
| 11 | `head_pitch_to_yaw.stl` | 1 | stock | print/ |
| 11 | `head_roll_mount.stl` | 1 | stock | print/ |
| 11 | `v330_head_head_yaw_to_roll.stl` | 1 | any | [head_v3.30](../print/mods/Twiglet/head_v3.30) |
| 12 | `v330_head_head_lower.stl` | 1 | wood-brown PETG | head_v3.30 |
| 12 | `v330_head_display_carrier_L/R.stl` | 1 + 1 | matte black | head_v3.30 |
| 12 | `v330_head_chin_collar_L/R.stl` | 1 + 1 | wood-brown | head_v3.30 |
| 13 | `v330_head_eye_bezel_L/R.stl` | 1 + 1 | matte black | head_v3.30 |
| 13 | `v330_head_head_upper.stl` | 1 | wood-brown PETG | head_v3.30 |
| 13 | `v330_head_snout.stl` | 1 | wood-brown | head_v3.30 |
| 14 | `FINAL_WIG.stl` | 1 | yellow/blond PLA (186.2 g) | [wig_v3.44](../print/mods/Twiglet/wig_v3.44) |

That is all 50 body v3.34 files, all 10 head v3.30 files and the wig.

**Stock files we don't print:** `trunk_bottom`, `trunk_top`, `body_front`, `body_middle_bottom`, `body_middle_top`, `body_back` (replaced by the torso frame and shells); `head`, `head_bot_sheet`, `head_yaw_to_roll` (replaced by head v3.30); `left_eye`, `right_eye`, `left/right_antenna_holder` (replaced by the digital eyes; no antennas); `neck_left_sheet`, `neck_right_sheet` (no neck-pitch servo since v3.5); `battery_pack_lid` (the battery goes in the frame tray).
- TODO: `left_roll_to_pitch` / `right_roll_to_pitch`. In our sim scene the roll-to-pitch link carries only the servo and its horns, with no printed part, and `v39_hip_bracket_L/R` sits on the hip-roll link. Confirm whether the stock parts are still needed.
- TODO: `left_cache` / `right_cache`, `speaker_interface`, `speaker_stand`, `bulb`, `flash_light_module`, `flash_reflector_interface`. Our records don't use them (no projector LEDs, speaker undecided).

## Requirements : 

You will need : 
- A soldering iron, and basic electronics tools and skills
- X m3 screws (TODO : add the exact number). Known so far:
  - 4× M3×8 for the chin collars
  - 4× M3×8 for the display carriers
  - 4× M3 for the head halves (length TODO)
  - plus the upstream leg/neck screws
- 8× M2×5 pan/button-head screws (displays to carriers)
- M2 screws for the upper-arm plates (count and length TODO)
- M3 heat-set inserts. Known so far:
  - 4× M3×5×4 for the chin collars
  - 4× M3×4×5 (Ø4 hole) for the display carriers
  - 4× for the head halves
  - plus upstream's
- 6× Feetech STS3032 (C001) arm servos and a 6 V buck regulator (for example Pololu D36V50F6) for them
- 2× Waveshare ESP32-S3-Touch-LCD-2.1 round displays, 2× SH1.0 12-pin cables (~150 mm), a 4-pin inline connector and ~30 cm of 26 AWG wire
- The 20×32×7 head roll bearing (stock size)
- Some wire, and zip ties
- Loctite Threadlocker blue 243
- 2-part epoxy (5- or 30-min) and medium CA glue
- 25 g of steel ballast for the head (for example 5× M8 hex nuts)
- 4× 3 mm steel rods or PLA filament, 12 mm long (wig pins)
- A felt hat (fabric, not printed)

> General note : Everytime you screw something in the motors metal against metal, you want to use a little loctite threadlocker. This will prevent the screws from coming loose due to the vibrations during the operation of the robot. It adds a little time to to the build, but you'll be glad you took the time ;)
>
> Don't use loctite with the plastic screws

> For the stock parts, you can refer to the upstream CAD at any time: https://cad.onshape.com/documents/64074dfcfa379b37d8a47762/w/3650ab4221e215a4f65eb7fe/e/0505c262d882183a25049d05
>
> Our parts have no Onshape CAD. Use the Blender sources in `print/mods/Twiglet/source/` and the images below.

## Steps :

### 0. Before you start

1. Print everything in the [parts table](#parts-to-step). Settings are in [print_guide.md](print_guide.md).
2. Configure every servo ID first ([configure_motors.md](configure_motors.md)). TODO: the IDs for the 6 arm servos.
3. Fit the heat-set inserts while the parts are loose: the stock ones from upstream, then the head ones (step 12).

### 1. Assemble the feet

<table>
  <tr>
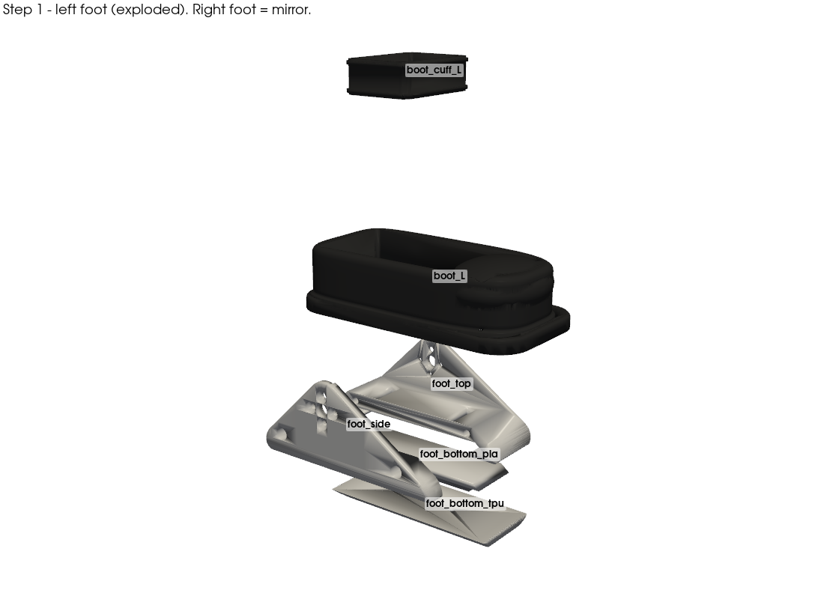
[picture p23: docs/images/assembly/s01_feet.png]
s01_feet
    <td> </td>
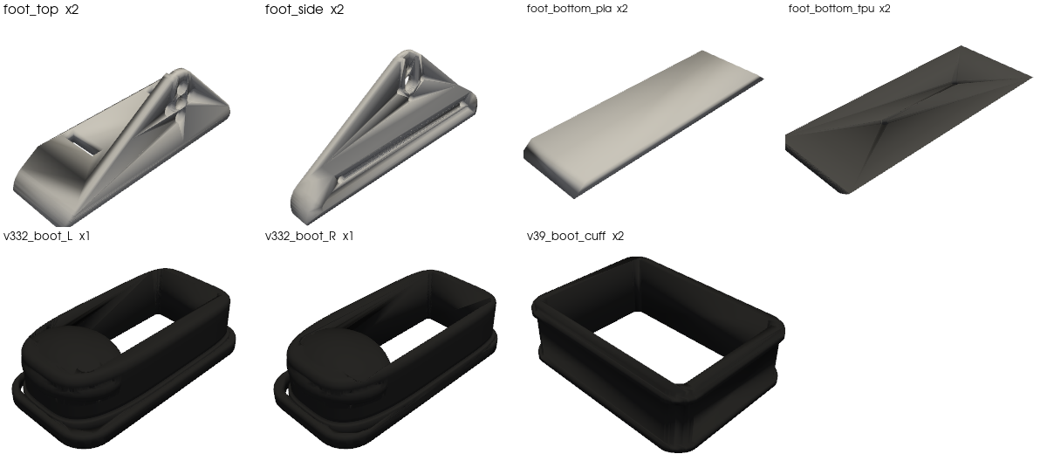
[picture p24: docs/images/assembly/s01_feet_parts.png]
s01_feet_parts
    <td> </td>
   </tr> 
</table>

**(upstream)** Unchanged: `foot_bottom_tpu` + `foot_bottom_pla` (2× M3×6 into inserts), then `foot_top` with the ankle motor. See [Assemble the feet](https://github.com/apirrone/Open_Duck_Mini/blob/v2/docs/assembly_guide.md#assemble-the-feet).

**(Twiglet)**
1. Fit the black `v332_boot_L/R` shell over the finished stock foot. TODO: how the boot is held (press fit or glue).
2. Slip `v39_boot_cuff` over the top of the stock foot.

- TODO: whether we fit the SS-10 foot switches. The sim does not model them.

### 2. Assemble the shins

<table>
  <tr>
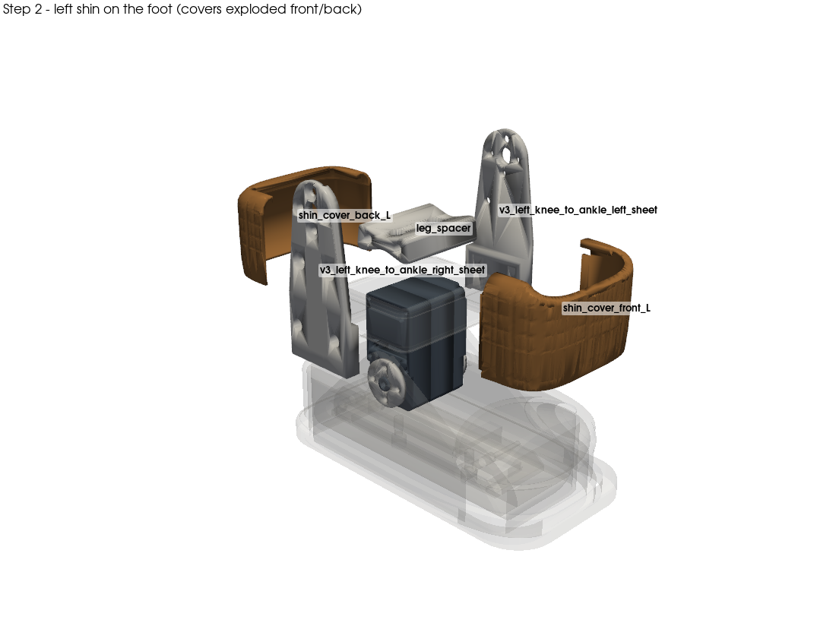
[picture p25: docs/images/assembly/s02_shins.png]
s02_shins
    <td> </td>
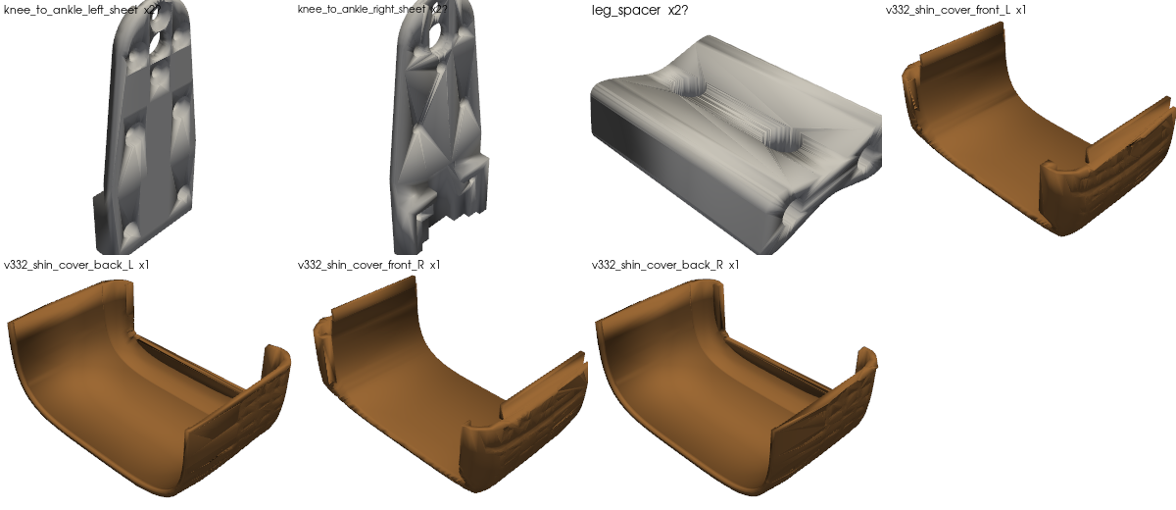
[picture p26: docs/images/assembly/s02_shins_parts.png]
s02_shins_parts
    <td> </td>
   </tr> 
</table>

**(upstream)** Unchanged: `leg_spacer` with M3 inserts and the stock knee-to-ankle sheets. See [Assemble the shins](https://github.com/apirrone/Open_Duck_Mini/blob/v2/docs/assembly_guide.md#assemble-the-shins).

**(Twiglet)** The wood-brown `v332_shin_cover_front/back_L/R` clamshell goes over the shin sheets, between the knee servo and the boot cuff:
1. Fit the back half behind the shin sheets.
2. Fit the front half. Its 1 mm lap lip keys into the back half.
3. Glue the halves to each other around the shin.

The shin-cover fit is from the v3.8 note. TODO: confirm it on the v3.32 covers.

### 3. Assemble the thighs 

<table>
  <tr>
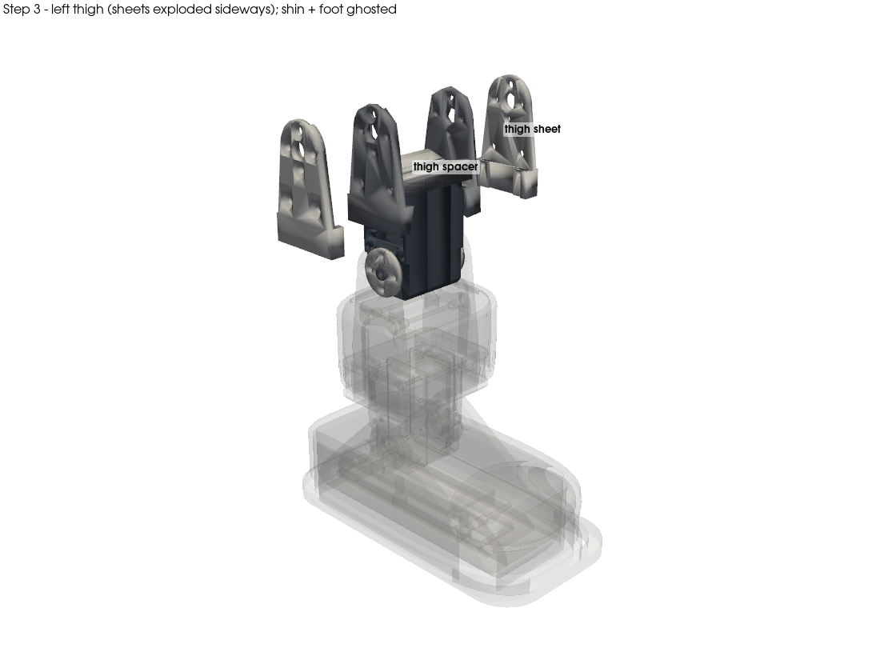
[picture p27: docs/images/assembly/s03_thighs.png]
s03_thighs
    <td> </td>
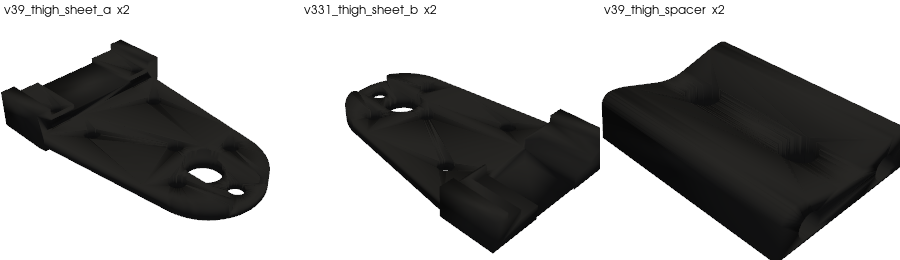
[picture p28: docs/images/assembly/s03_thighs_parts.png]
s03_thighs_parts
    <td> </td>
   </tr> 
</table>

**(upstream)** Same motor orientation as upstream (important for the zero position). See [Assemble the thighs](https://github.com/apirrone/Open_Duck_Mini/blob/v2/docs/assembly_guide.md#assemble-the-thighs).

**(Twiglet)** Our thigh is 22 mm shorter than stock (v3.1). It uses the black `v39_thigh_sheet_a` ×2, `v331_thigh_sheet_b` ×2 and `v39_thigh_spacer` ×2 instead of the stock sheets and spacer.
- TODO: the screw list.
- TODO: which sheet goes on which side.

### 4. Assemble the hips

<table>
  <tr>
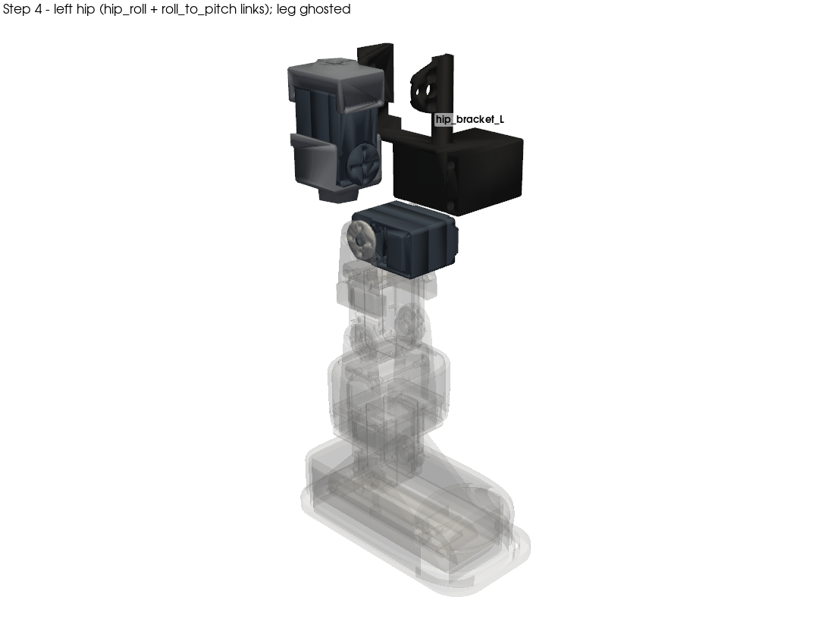
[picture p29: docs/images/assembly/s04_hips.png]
s04_hips
    <td> </td>
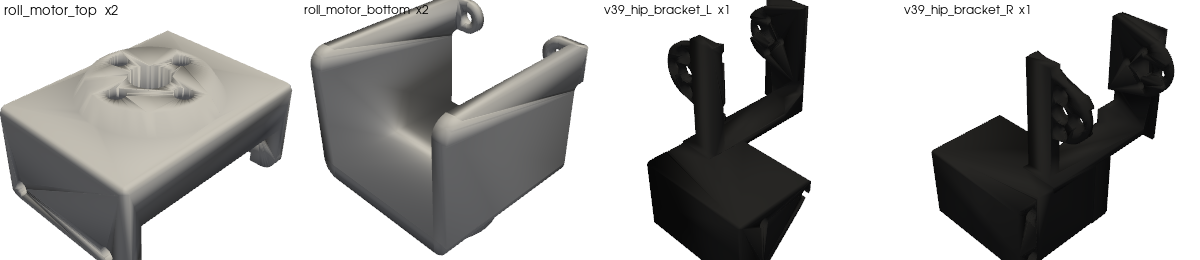
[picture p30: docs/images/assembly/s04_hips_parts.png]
s04_hips_parts
    <td> </td>
   </tr> 
</table>

**(upstream)** `roll_motor_top` to the hip_yaw servo, then hip_roll and the sub-assembly. See [Assemble the hips](https://github.com/apirrone/Open_Duck_Mini/blob/v2/docs/assembly_guide.md#assemble-the-hips).

**(Twiglet)** The black `v39_hip_bracket_L/R` are the load-path hip parts. They print like the stock `*_roll_to_pitch` (sleeve axis vertical).
- In the sim scene each bracket sits on the hip-roll link, next to the hip-roll servo.
- TODO: confirm that they replace `left/right_roll_to_pitch`, and give the mounting screws.

### 5. Assemble the trunk

<table>
  <tr>
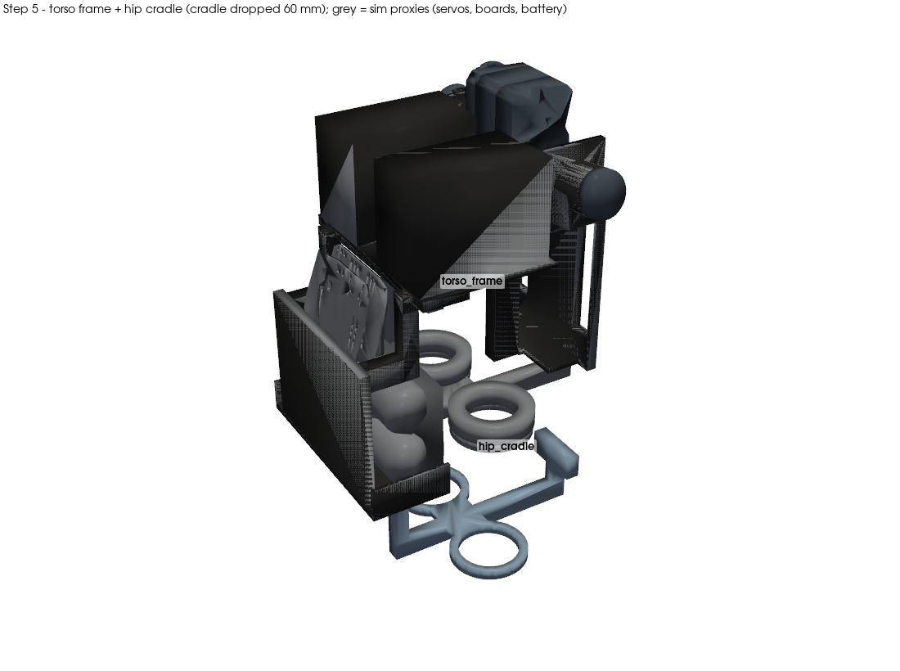
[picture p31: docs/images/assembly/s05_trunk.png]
s05_trunk
    <td> </td>
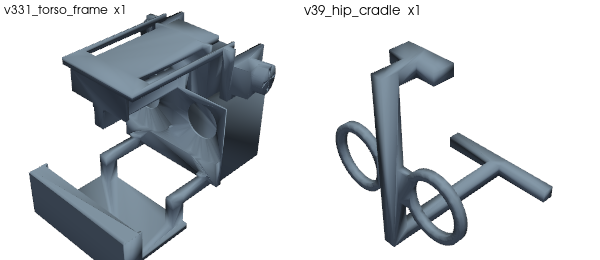
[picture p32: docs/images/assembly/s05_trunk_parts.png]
s05_trunk_parts
    <td> </td>
   </tr> 
</table>

**(Twiglet)** We do **not** use `trunk_bottom` / `trunk_top`. Our trunk is made of:
- `v331_torso_frame`: battery tray, back rail, hip deck, the two strut columns, the fixed neck post with the head-pitch cup cradle, and the shoulder bosses. Since v3.5 there is no neck-pitch servo.
- `v39_hip_cradle` (hidden; printed flipped, seats up, with T-arms). TODO: exactly what it carries and how it attaches to the frame.

The `roll_motor_bottom` parts are still the stock ones. The hips are 20 mm further forward than stock and the battery further back (v3.1), and the legs are 100 mm apart.

- TODO: the exact trunk steps. How the hip-yaw servos and `roll_motor_bottom` mount on the hip cradle and frame, which screws, which inserts, and whether the stock trunk bearings are still used.
- Upstream step for reference: [Assemble the trunk](https://github.com/apirrone/Open_Duck_Mini/blob/v2/docs/assembly_guide.md#assemble-the-trunk).

### 6. Mount the legs on the trunk

<table>
  <tr>
    <td> s06_legs_on_trunk</td>
   </tr> 
</table>

**(Twiglet)** Mount both finished legs (from the hip-yaw servo down) on the hip cradle / torso frame, 100 mm apart. Upstream equivalent: the end of [Assemble the hips](https://github.com/apirrone/Open_Duck_Mini/blob/v2/docs/assembly_guide.md#assemble-the-hips). TODO: the exact interface and fasteners.

### 7. Electronics

<table>
  <tr>
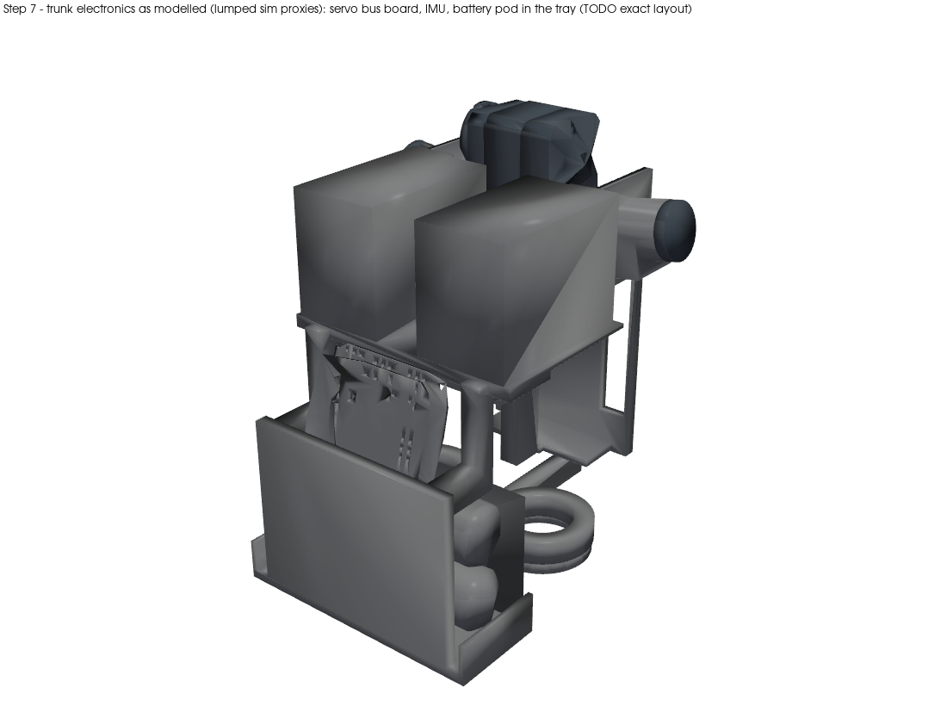
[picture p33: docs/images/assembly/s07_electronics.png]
s07_electronics
    <td> </td>
   </tr> 
</table>

The image only shows where the sim puts the masses. The real layout is a TODO.

#### Mount the servo driver board

**(upstream)** TODO take a photo

**(Twiglet)** The Waveshare bus servo adapter is the same as upstream. TODO: where it mounts in our torso.

#### Mount the IMU

**(upstream)** BNO055, same as upstream. See [Mount the IMU](https://github.com/apirrone/Open_Duck_Mini/blob/v2/docs/assembly_guide.md#mount-the-imu). Mounting it in its natural orientation is better, and the orientation can be configured later.

**(Twiglet)** TODO: where the IMU mounts on `v331_torso_frame`.

#### Arm power

The STS3032 maximum is 7.4 V and a full 2S pack is 8.4 V. **Feed the arm branch through a 6 V buck regulator** (for example Pololu D36V50F6, 6 V 5.5 A). Share the data line and ground with the STS3215 bus. TODO: where the buck mounts.

#### Wiring

Here is the upstream global electronics schematic for reference. Ours is the same, plus the arm 6 V branch and the eye screens. TODO: an updated diagram.

<table>
  <tr>
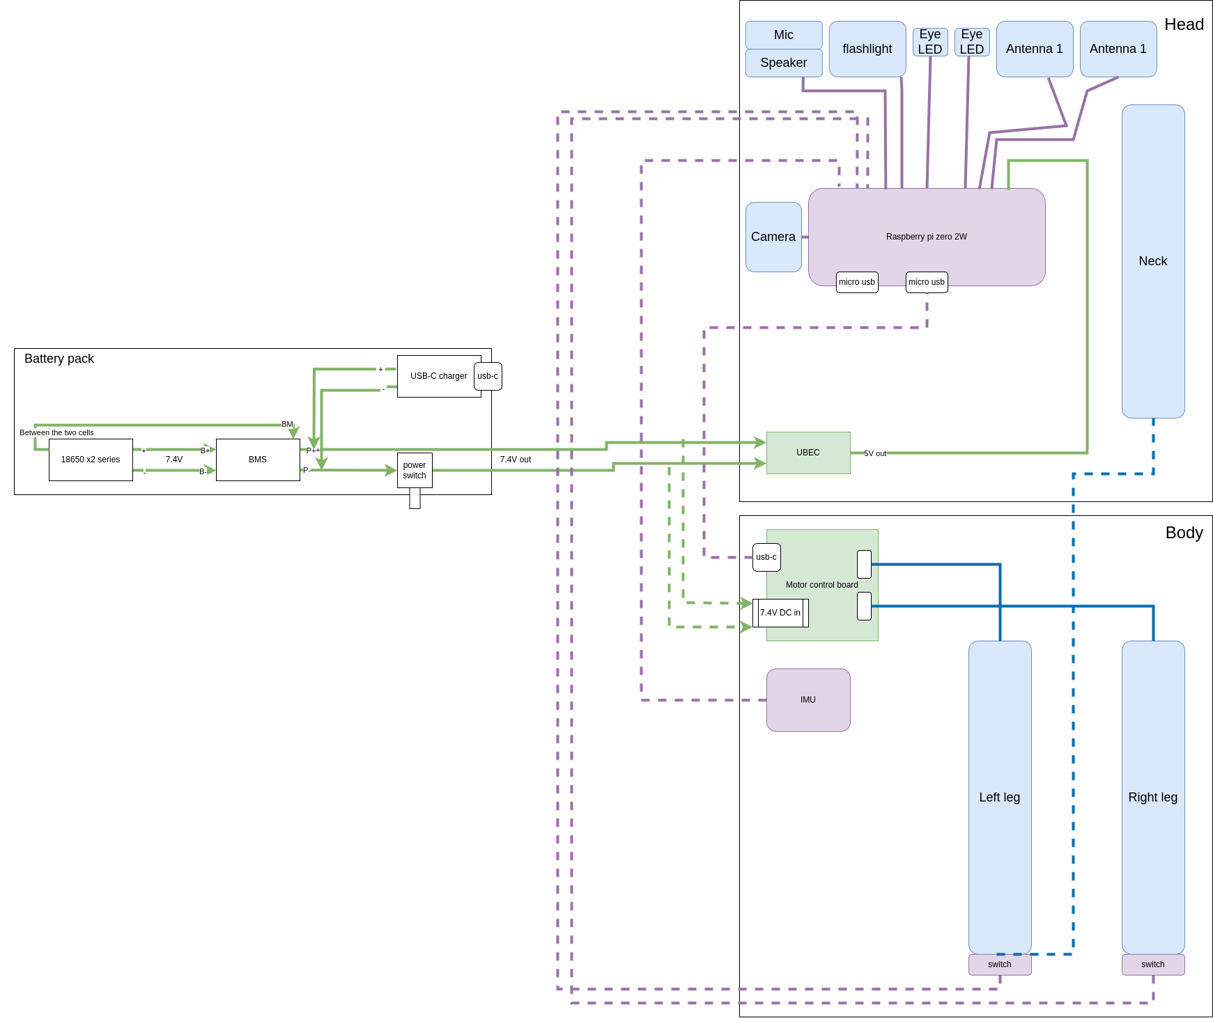
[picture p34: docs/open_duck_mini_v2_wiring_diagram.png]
    <td> </td>
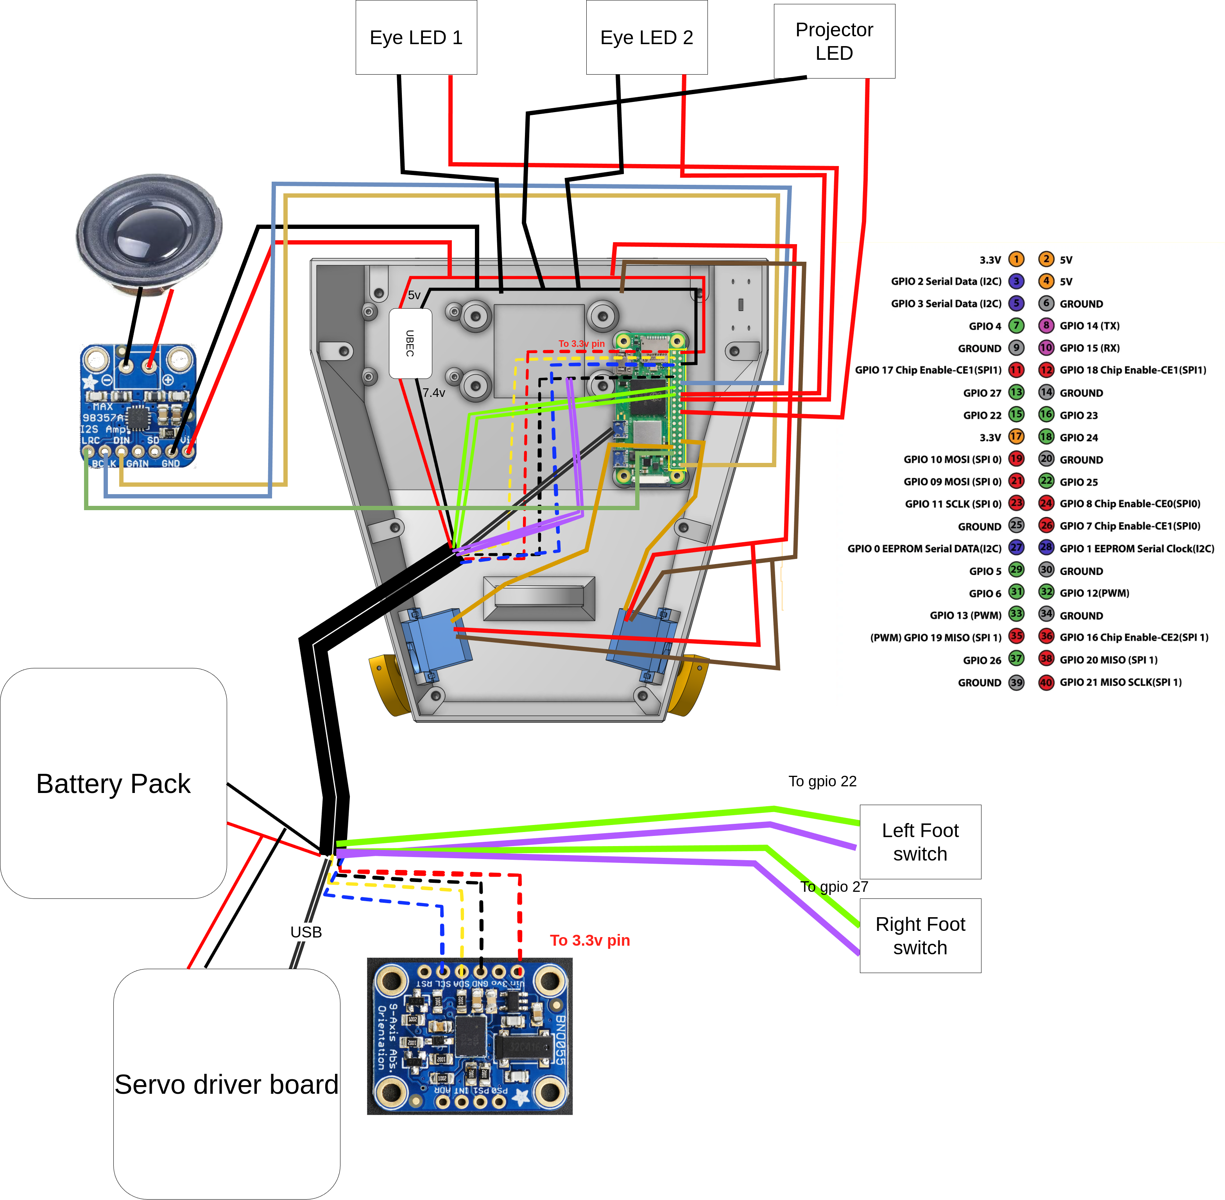
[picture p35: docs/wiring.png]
    <td> </td>
   </tr> 
</table>

For the feet wiring, see [upstream](https://github.com/apirrone/Open_Duck_Mini/blob/v2/docs/assembly_guide.md#electronics) (only if the foot switches are fitted, TODO).

Here is the pin mapping on the Pi Zero header. It is upstream's mapping minus the parts we don't use, plus the eyes.

| **Eyes (UART)** | **Pi Zero Header Pin** | **Pi Zero Function** |
|:---:|:---:|:---:|
|  L + R board RXD (12-pin #10) | 8 | GPIO 14 (TXD) |
|  L board TXD (12-pin #9) | 10 | GPIO 15 (RXD) |
|  GND (12-pin #1) | 6 | GND |
|  VBus 5V (12-pin #2) | 5 V rail | 5V |
| | | |
|  **Foot Switches** (TODO: fitted?) | | |
| Left Foot | 15 | GPIO 22 |
| Right Foot | 13 | GPIO 27 |
| GND | 9 | GND |
| | | |
| **BNO055** | | |
| VIN | 1 | 3V3 |
| 3VO | NC | - |
| GND | 9 | GND |
| SDA | 3 | GPIO 2 |
| SCL | 5 | GPIO 3 |
| RST | NC | - |

- Not used:
  - the eye/projector LEDs (pins 16/18/22)
  - the antenna PWM servos (pins 32/33). The 2 SG90 antenna servos are omitted.
- TODO: whether we keep the MAX98357A speaker (pins 35/12/40).
- Eye UART setup on the Pi:
  - `raspi-config` → Serial: login shell **no**, hardware **yes**.
  - Add `dtoverlay=disable-bt` to `/boot/firmware/config.txt`.
  - The servo bus runs over USB, so the GPIO UART is free.
  - Unplug the eye board's "UART" USB-C while the Pi drives it.
- Budget 0.5 A on the 5 V rail for the two eye boards. Their draw is not measured.

#### Battery pack

> To be safe, make sure your cells are charged to the same voltage before placing them in the holder.

**(upstream)** Same 2× 18650, holder, 2S BMS, charger and switch. See [Battery pack](https://github.com/apirrone/Open_Duck_Mini/blob/v2/docs/assembly_guide.md#battery-pack).

**(Twiglet)** The battery pod sits in the `v331_torso_frame` battery tray, behind the hips and under the kilt. It was moved 18 mm back and 7 mm lower than stock (v3) as a counterweight, and the sims assume it is there. Upstream's `battery_pack_lid` is not used. TODO: how the pack is held in the tray.

### 8. Fit the torso shells and chest leaves

<table>
  <tr>
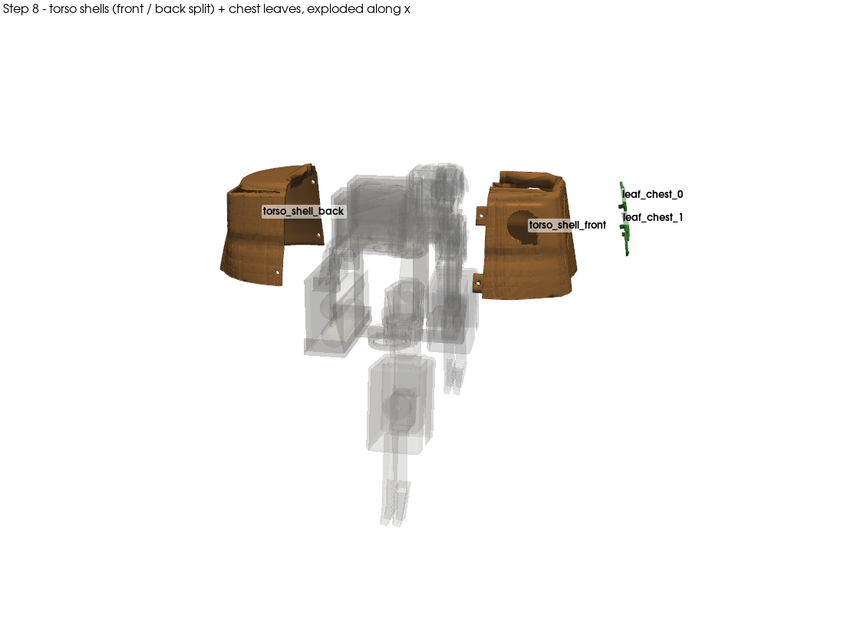
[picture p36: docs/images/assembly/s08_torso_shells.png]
s08_torso_shells
    <td> </td>
   </tr> 
</table>

**(Twiglet)** This replaces upstream's `body_front`, `body_middle_bottom`, `body_middle_top` and `body_back`.
1. Fit `v331_torso_shell_back` and `v331_torso_shell_front` around `v331_torso_frame`. The shell is split front/back at x = −20 mm with tabs, and has a closed 2 mm top lid. TODO: fasteners.
   - The front shell has two shoulder-boss holes. TODO: confirm whether the shells must go on before the shoulder servos (step 9) or can go on after.
2. Glue `v332_chest_vine` and the leaves `v39_leaf_M` ×1 / `v39_leaf_S` ×2 (veined face out, peg into the socket) onto the front shell.

### 9. Assemble the arms

<table>
  <tr>
    <td> s09_arms</td>
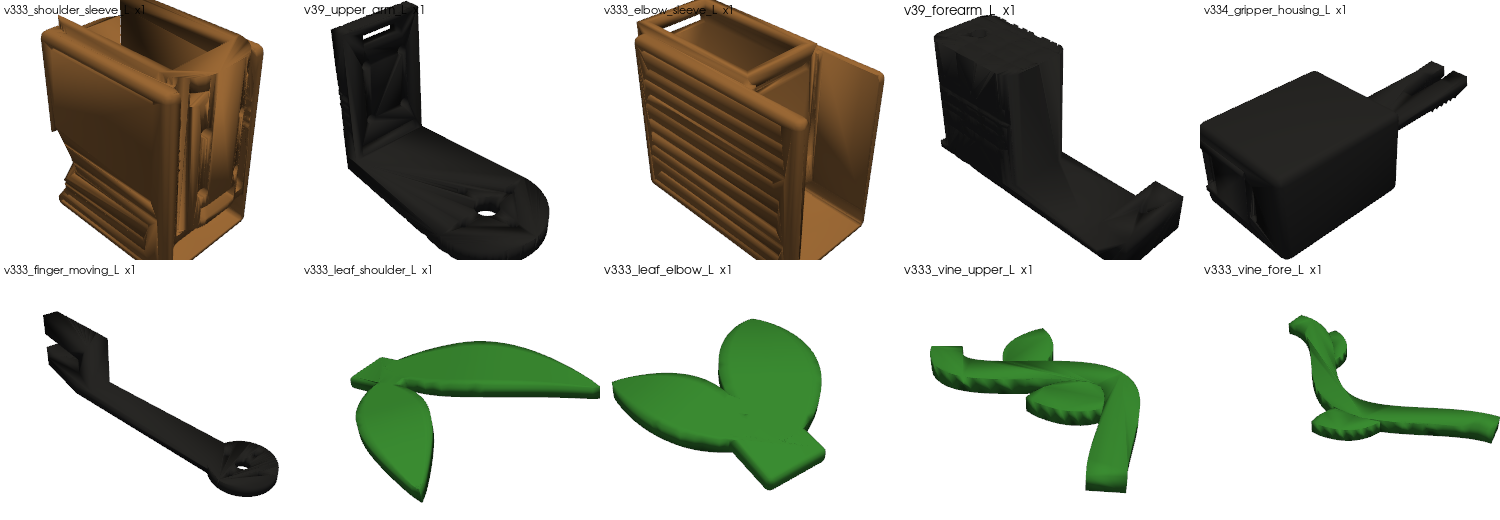
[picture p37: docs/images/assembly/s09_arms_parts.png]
s09_arms_parts
    <td> </td>
   </tr> 
</table>

**(Twiglet)** This step is new. Each arm has 3 Feetech **STS3032** (C001) micro bus servos: shoulder pitch, elbow and gripper. They are on the same TTL bus as the STS3215s, on the 6 V branch (step 7). The elbow servo is flipped: its horn faces inward, so the black upper-arm plate runs down the inner side (v3.1).

Parts per side:
- `v333_shoulder_sleeve` and `v333_elbow_sleeve` (wood-brown blocks)
- `v39_upper_arm` and `v39_forearm` (black brackets)
- `v334_gripper_housing` (black, 36×47×57 mm, 1.6 mm walls, open bottom)
- `v333_finger_moving` (black, on the gripper servo horn)
- `v333_leaf_shoulder`, `v333_leaf_elbow`, `v333_vine_upper` and `v333_vine_fore` (green)

Steps:
1. Fix the shoulder servo to the shoulder boss on `v331_torso_frame` and slide on the shoulder sleeve. TODO: screws.
2. Fix `v39_upper_arm` with M2 screws to the sleeve bottom and the servo ears. This is from the v3.1/v3.8 notes: TODO confirm it on the v3.33 sleeves, and give the screw length and count.
3. Fit the elbow servo, the elbow sleeve and `v39_forearm`. TODO: screws.
4. Slide the gripper housing over the gripper servo (press-fit sleeve; the fit check gives the same overlap as rev C), then mount `finger_moving` on the horn. TODO: confirm that the fixed finger (prong) is part of the housing. There is no separate STL for it.
5. Glue the vines on the front faces of the upper-arm and forearm blocks. Glue the leaves into their sockets.

TODO: the arm servo IDs (see [configure_motors.md](configure_motors.md)).

Check: at rest the elbows rest against the kilt band, in its arm slots (step 10). The sim arm sweeps are clear of the shell, kilt and head inside the soft limits ([experiments/twiglet_geom](../experiments/twiglet_geom)).

### 10. Fit the kilt

<table>
  <tr>
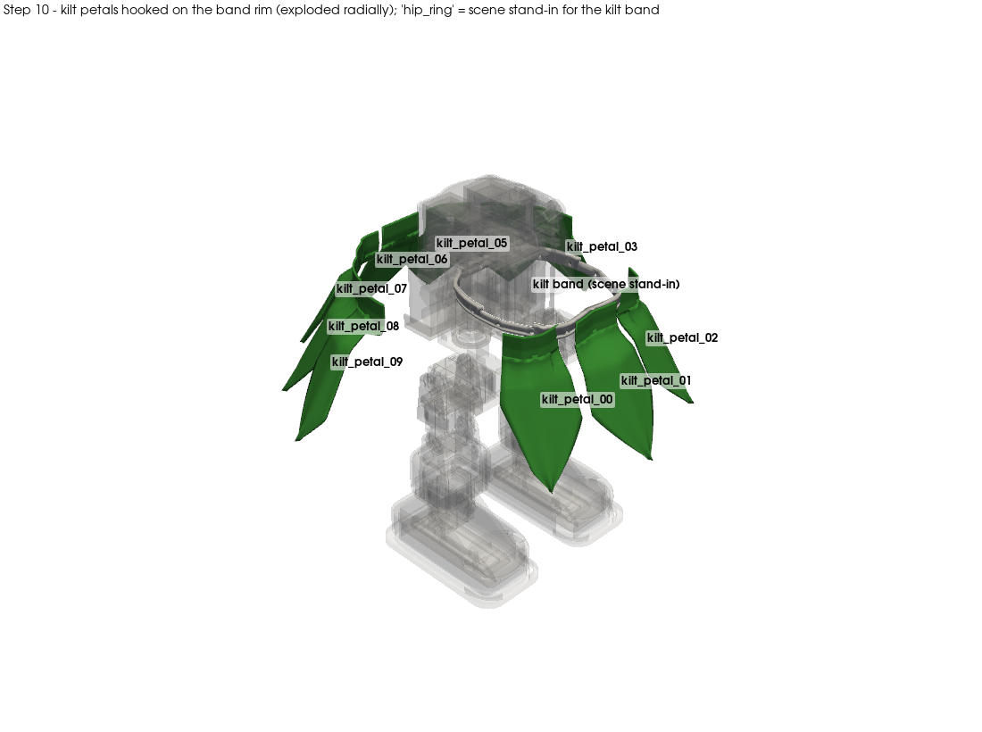
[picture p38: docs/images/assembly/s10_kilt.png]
s10_kilt
    <td> </td>
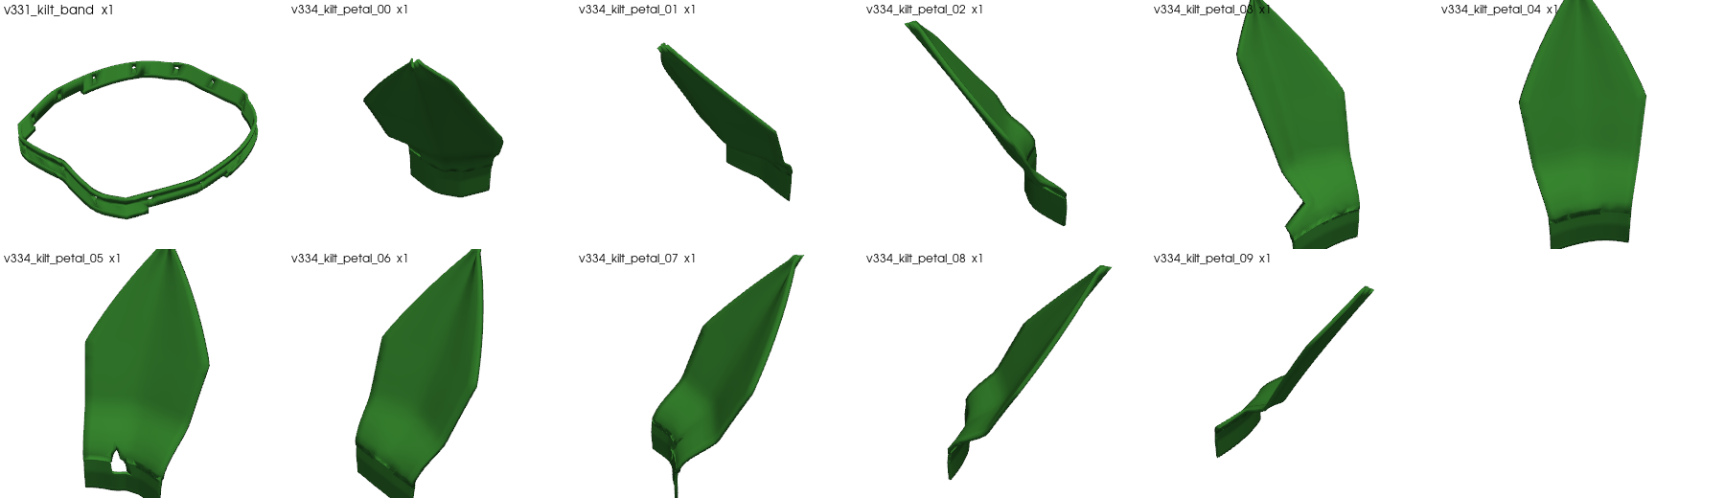
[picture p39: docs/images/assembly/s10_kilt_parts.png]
s10_kilt_parts
    <td> </td>
   </tr> 
</table>

**(Twiglet)**
1. Fit the green `v331_kilt_band` at the hips. It is the v3 hip ring reprinted with a rolled rim on top, with arm slots at 46–93° either side for the elbows. TODO: how the band is fixed to the trunk.
2. Hook the 10 `v334_kilt_petal_00..09` over the band rim. Each petal's top lip hooks over the rim like a hinge and rests against the rim face, so the petals swing freely (the front petals can be pushed out by the feet at extreme knee + thigh angles; that's intended). Petals 00–02 are the front ones.
   - TPU petals don't swing; they flex and can be glued straight onto the rim.
   - TODO: whether the PLA petals need any retention.

### 11. Assemble the neck and head mechanism

<table>
  <tr>
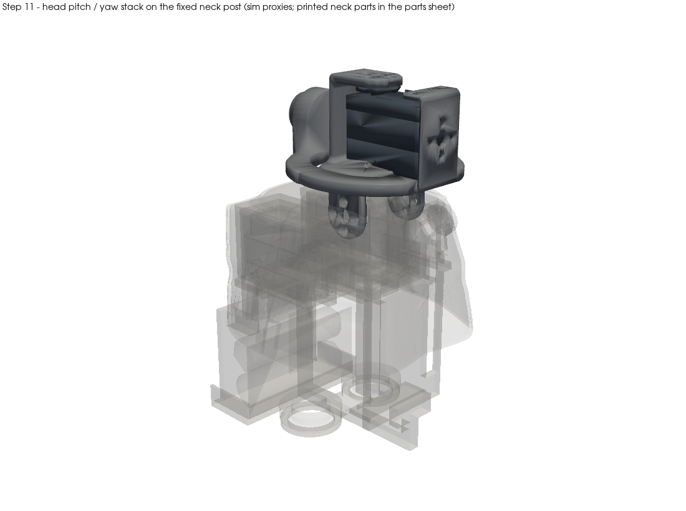
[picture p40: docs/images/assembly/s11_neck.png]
s11_neck
    <td> </td>
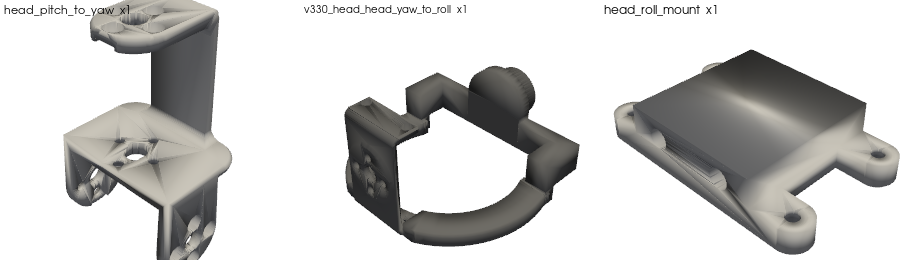
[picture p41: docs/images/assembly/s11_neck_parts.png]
s11_neck_parts
    <td> </td>
   </tr> 
</table>

**(Twiglet)** There are no neck sheets and no neck-pitch servo (removed in v3.5). The head-pitch servo hangs below its axis and is bolted into the fixed head-pitch cup cradle on `v331_torso_frame`. TODO: the mounting screws. The upstream neck step ([Assemble the neck](https://github.com/apirrone/Open_Duck_Mini/blob/v2/docs/assembly_guide.md#assemble-the-neck)) does not apply.

**(upstream)** First, mount `head_pitch_to_yaw` (stock). Then, independently, mount the yaw-to-roll part and `head_roll_mount` (stock) to the head_roll dof, in the same order as [Assemble the head mechanism](https://github.com/apirrone/Open_Duck_Mini/blob/v2/docs/assembly_guide.md#assemble-the-head-mechanism).

**(Twiglet)** Print and use `v330_head_head_yaw_to_roll` **instead of** the stock `head_yaw_to_roll` and the older `v39_head_yaw_to_roll`.
- The roll bearing is the same 20×32×7 bearing, but it now presses into the housing in `v330_head_head_lower`, 12.1 mm further forward on the same roll axis (step 12).
- The new hub slides 7 mm into the bearing.
- Route the head cable down the **side** of the neck, not the back. In head v2 the radial gap at the collar opening was 17–29 mm at the sides and ~0 at the back (TODO: re-check on v3.30).

### 12. Head v3.30: inside head_lower

<table>
  <tr>
    <td> s12_head_inside</td>
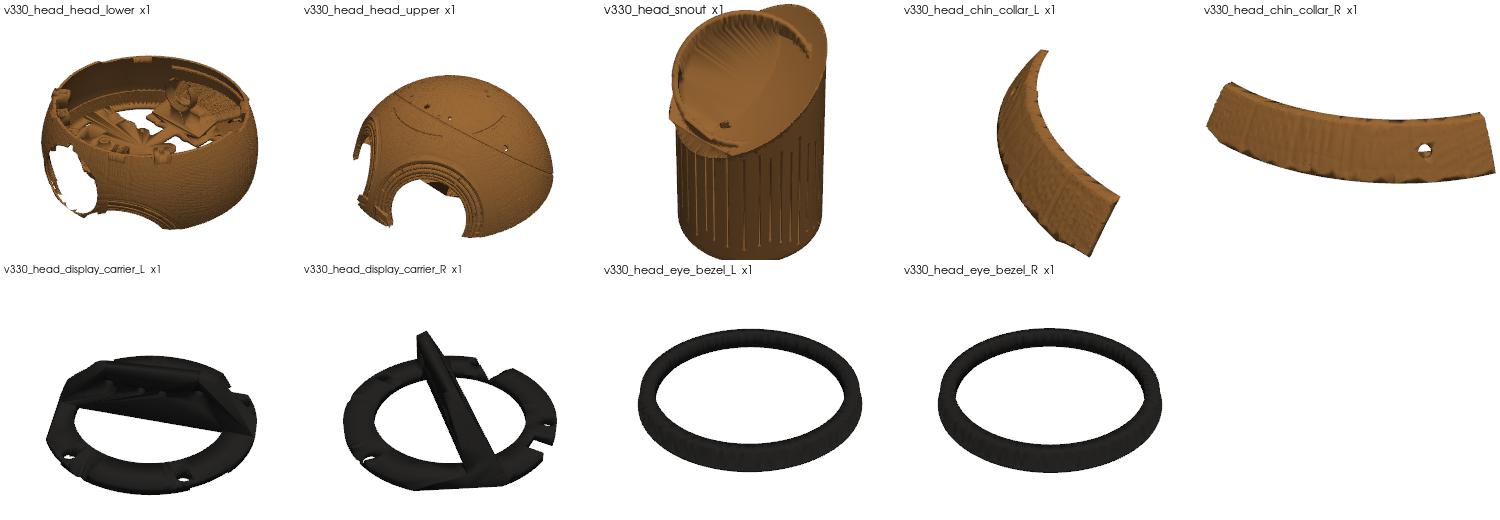
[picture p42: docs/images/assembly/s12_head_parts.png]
s12_head_parts
    <td> </td>
   </tr> 
</table>

**(Twiglet)** This replaces upstream's `head.stl` and `head_bot_sheet`. Work with the head upside down on the bench.

1. **Inserts:**
   - 4 for the head-half joint
   - 4× M3×5×4, pressed vertically from below into the 4 bosses inside the `head_lower` rim, for the chin collars
   - 4× M3×4×5 in the `head_lower` deck posts, for the display carriers
2. **Bearing:** press the 20×32×7 roll bearing into the `head_lower` housing. The outer ring shows through the housing's bottom window; that is intended (a 282° wrap and a rear lip hold it).
3. **Ballast (required):** epoxy 25 g of steel on the ledge inside the back of `head_lower`, against the shell, centred on the rear centreline within ±30°. For example, use 5× M8 hex nuts standing on edge, or 5× 5 g wheel weights cut to 14 mm tall or less. Weigh it: it must be 23–27 g. The sims assume exactly this (head-pitch hold ≥ 2×; without it the hold drops to 1.9×).
4. **Pi Zero 2W:** on its standoffs in `head_lower` (head v2/v3 note: 3 screws go straight in, the 4th needs a ~20° tilted driver; 4× M2.5). The left display ends 0.6 mm from the Pi in the head v3 check. TODO: confirm the Pi mounting on v3.30.
   - The head v2 notes also put "the relocated ODM board" on top of the deck with 4× M2.5. TODO: confirm which board and whether that still applies.
5. **Eyes** (from the head v3 digital-eyes notes; TODO confirm on v3.30):
   1. Fix each Waveshare ESP32-S3-Touch-LCD-2.1 to its `display_carrier` with 4× M2×5 through the carrier ring into the board's standoffs. The carrier notch goes over the 12-pin header.
   2. Plug in the 12-pin cable.
   3. Drop each pod straight down into `head_lower`: the glass sits in its socket and the foot plate on the two posts. Fit 2× M3×8 from above into the deck-post inserts.
   4. Run the cables through the cable exit and along the deck to the Pi. Zip-tie them through the carrier slots.
   - Firmware and first-time setup (`SIDE`, `ROT`, `CENTER`, `SAVE`) are in [experiments/twiglet_eyes](../experiments/twiglet_eyes).
6. **Mount the head** on the neck: the hub of `v330_head_head_yaw_to_roll` slides 7 mm into the bearing, and `head_lower` fixes to the stock `head_roll_mount`. Head v2 used 4× M3, vertically from below, into the copied roll-mount bosses. TODO: confirm on v3.30. Upstream: [Head](https://github.com/apirrone/Open_Duck_Mini/blob/v2/docs/assembly_guide.md#head).
7. **Chin collars:** fix each collar with 2× M3×8 from below, through its 2 inner ledges, into the rim inserts (4 screws in total).

### 13. Close the head

<table>
  <tr>
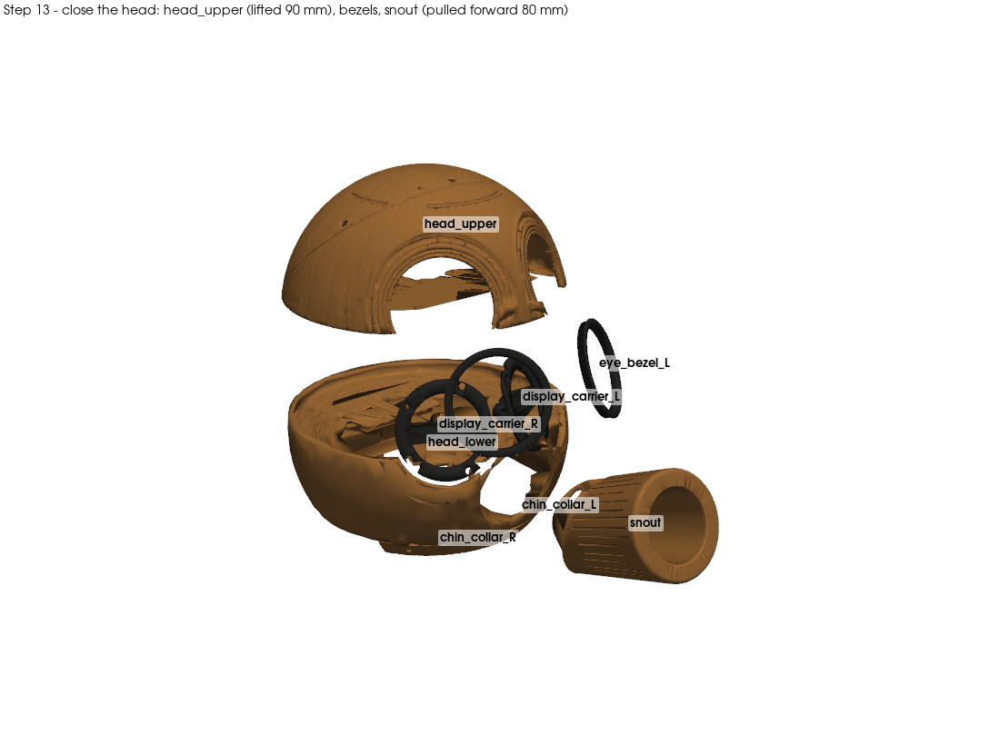
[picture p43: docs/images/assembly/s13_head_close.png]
s13_head_close
    <td> </td>
   </tr> 
</table>

1. **Bezels:** glue the black `eye_bezel_L/R` into `head_upper`'s eye openings (CA or epoxy), flat face out, 0.8 mm proud. An optional foam ring goes on the bezel's back. (Head v3 digital-eyes note; TODO confirm on v3.30.)
2. **Close:** lower `head_upper` straight down over the eye pods onto `head_lower`, then fit 4 M3 screws from below into the inserts (length TODO; head v2 used a ball-end hex at ~15°).
3. **Snout:** dry-fit it so the key tab sits in the `head_lower` key slot and the root lies flush on the ball, then glue it (CA or epoxy). **Glue it to head_lower only.** head_upper still lifts straight off with the snout glued in.

**Service:** head_upper lifts straight up (with the bezels and the wig). Then undo 2× M3, lift a pod straight out, and undo its 4× M2 on the bench.

### 14. Wig and hat

<table>
  <tr>
    <td> s14_wig</td>
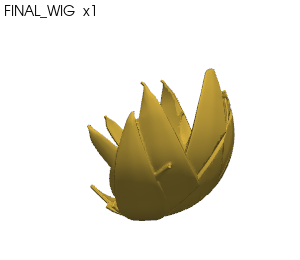
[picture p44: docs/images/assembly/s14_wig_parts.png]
s14_wig_parts
    <td> </td>
   </tr> 
</table>

**(Twiglet)** `print/mods/Twiglet/wig_v3.44/FINAL_WIG.stl` (hair v3.44, variant c14) is one piece of yellow/blond PLA at 4.5 % lightning infill, 186.2 g, 243 × 246 × 240 mm as oriented (fits a P1S; crown axis tilted 38° from straight down for the least support, ~473 cm³ of support). Closed crown, walls ≥ 2.39 mm, watertight single body.

wig v3.43 (left) vs v3.44 c14 (right), three views

1. Glue the four 3 mm × 12 mm rods 5 mm deep into the 4 blind holes in the wig.
2. Dry-fit. The 7 mm rod ends drop into the 4 vertical 3.2 mm holes (7.5 mm deep) in `head_upper`. The keyed tongue only fits one way, with the long arc at the front.
3. Glue it with 2-part epoxy: a thin bead on the crown seat band, the tongue and the pin holes. Push it down and tape it for 1 h.
   - For a removable wig, use pins, tongue and 3 dots of E6000 or hot glue.
4. **Hat:** pull the felt hat on so its edge sits in the recessed band all the way round (the hat seat on the wig/head is an 8 mm smooth crown plus a 4.5 mm recessed band, v3.27): front edge just above the fringe roots, down over the left ear, tail flopping to the robot's left. The hat is not modelled in the renders or the sim (head v2 budgeted ~45 g of felt). TODO: whether the head v2 hat magnets / stitch holes still exist on v3.30.

### 15. Final checks

- Weigh the robot. The current sim model (`experiments/twiglet_sim/models/twiglet_v3_v334_wig344.xml`) assumes 2.753 kg in total, with the head at 0.814 kg including the ballast and the wig. TODO: compare with the real build.
- Move every joint by hand through its soft limits and check that nothing binds. The sim sweeps say the arms are clear of the shell, kilt and head, and the wig is clear of the arms inside the head soft limits ([experiments/README.md](../experiments/README.md)).

Et voila :) 

> Now that your duck is fully assembled, you setup the raspberry pi and the runtime software [here](https://github.com/apirrone/Open_Duck_Mini_Runtime). TODO: add the arm servos and the eyes to the runtime.

## Remaining TODOs (collected)

- Screw counts and lengths for the legs, trunk, arms and head halves; insert count total.
- Shin sheet and leg spacer quantities; whether `left/right_roll_to_pitch` are still printed; the other unused stock parts.
- Hip-cradle / trunk / leg fasteners; whether the stock trunk bearings are still used.
- Where the servo board, IMU, 6 V buck and Pi go; how the battery pod is held; an updated wiring diagram.
- Boot retention; kilt band fixing; PLA petal retention; torso shell fasteners and order vs the shoulder servos.
- Confirm the v3.30 head details taken from the head v2 / v3 notes (Pi mount, relocated board, roll-mount screws, bezel gluing, hat anchors).
- Arm servo IDs; foot switches; speaker.

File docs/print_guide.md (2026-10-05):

# Print guide

> This is based on the [Open Duck Mini v2 print guide](https://github.com/apirrone/Open_Duck_Mini/blob/v2/docs/print_guide.md). A verbatim copy is in [upstream/print_guide.md](upstream/print_guide.md).

You can find the `.stl` files under the `print/` directory at the root of this repo:
- the upstream Open Duck Mini v2 stock parts are in `print/`, unchanged
- our Twiglet parts are in `print/mods/Twiglet/`

Upstream rule for the stock parts: standard PLA with 15% infill, except `foot_bottom_tpu.stl`, which is TPU at 40% infill.

Our parts have their own settings, listed below. The head and wig settings are **required**: the sims assume them, and heavier prints break the head-pitch and balance margins.

Printer used for the checks: Bambu P1S with a 0.4 mm nozzle. Every part fits 256 × 256 × 256 mm. Every Twiglet STL is exported in its print orientation, with z = 0 on the bed.

## Parts to print

### Stock Open Duck Mini v2 parts (`print/`)

Used, unchanged:
- foot_top.stl x2
- foot_side.stl x2
- foot_bottom_pla.stl x2
- foot_bottom_tpu.stl x2 (TPU)
- knee_to_ankle_left_sheet.stl (TODO: count. Upstream prints x4, but our thighs use our own sheets.)
- knee_to_ankle_right_sheet.stl (TODO: count, as above)
- leg_spacer.stl (TODO: count. Upstream prints x4.)
- roll_motor_bottom.stl x2
- roll_motor_top.stl x2
- head_pitch_to_yaw.stl x1
- head_roll_mount.stl x1

Unknown (TODO):
- left_roll_to_pitch.stl / right_roll_to_pitch.stl: `v39_hip_bracket_L/R` probably replace them.
- left_cache.stl / right_cache.stl

**Not used** (replaced by Twiglet parts, or the feature is dropped):
- trunk_bottom, trunk_top → `v331_torso_frame` + `v39_hip_cradle`
- neck_left_sheet, neck_right_sheet: there has been no neck-pitch servo since v3.5
- head_yaw_to_roll → `v330_head_head_yaw_to_roll`
- head, head_bot_sheet → the head v3.30 parts
- left/right_antenna_holder: no antennas
- body_front, body_middle_bottom, body_middle_top, body_back, battery_pack_lid → the torso shells and frame
- bulb, flash_light_module, flash_reflector_interface, left_eye, right_eye, speaker_interface, speaker_stand → the digital eyes (TODO: speaker?)

### Twiglet: body v3.34 (`print/mods/Twiglet/body_v3.34/`)

This table comes from [print_sheet_body_v334.md](../print/mods/Twiglet/body_v3.34/print_sheet_body_v334.md), which also has gram and hour estimates (rough, no slicer run). Layers are in mm. "Wood-brown" can be wood-fill PLA.

| File | Qty | Material / colour | Layer | Walls / infill | Orientation / supports |
|---|---|---|---|---|---|
| `v333_shoulder_sleeve_L.stl` | 1 | PLA wood-brown (wood-fill ok) | 0.2 | 4 walls, 30% | outer cap face down (as exported); tree supports inside the open bottom / servo pocket |
| `v333_shoulder_sleeve_R.stl` | 1 | PLA wood-brown (wood-fill ok) | 0.2 | 4 walls, 30% | outer cap face down (as exported); tree supports inside the open bottom / servo pocket |
| `v333_elbow_sleeve_L.stl` | 1 | PLA wood-brown (wood-fill ok) | 0.2 | 4 walls, 30% | outer cap face down (as exported); tree supports inside the skirt / servo pocket |
| `v333_elbow_sleeve_R.stl` | 1 | PLA wood-brown (wood-fill ok) | 0.2 | 4 walls, 30% | outer cap face down (as exported); tree supports inside the skirt / servo pocket |
| `v334_gripper_housing_L.stl` | 1 | PLA/PETG black | 0.2 | 4 walls, 30% | box inner (body-side) face down (as exported, lay-flat); supports under the prong slot + finger opening |
| `v334_gripper_housing_R.stl` | 1 | PLA/PETG black | 0.2 | 4 walls, 30% | box inner (body-side) face down (as exported, lay-flat); supports under the prong slot + finger opening |
| `v333_finger_moving_L.stl` | 1 | PLA/PETG black | 0.16 | 4 walls, 100% | flat side down (as exported, lay-flat); no supports |
| `v333_finger_moving_R.stl` | 1 | PLA/PETG black | 0.16 | 4 walls, 100% | flat side down (as exported, lay-flat); no supports |
| `v333_leaf_shoulder_L.stl` | 1 | PLA green (or TPU 95A) | 0.12 | 2 walls, 100% | back face down; tree supports under the curled tip |
| `v333_leaf_shoulder_R.stl` | 1 | PLA green (or TPU 95A) | 0.12 | 2 walls, 100% | back face down; tree supports under the curled tip |
| `v333_leaf_elbow_L.stl` | 1 | PLA green (or TPU 95A) | 0.12 | 2 walls, 100% | back face down; tree supports under the curled tip |
| `v333_leaf_elbow_R.stl` | 1 | PLA green (or TPU 95A) | 0.12 | 2 walls, 100% | back face down; tree supports under the curled tip |
| `v333_vine_upper_L.stl` | 1 | PLA green | 0.12 | 2 walls, 100% | flat (1.6 mm strip), no supports; glue on the upper-arm block front face |
| `v333_vine_upper_R.stl` | 1 | PLA green | 0.12 | 2 walls, 100% | flat (1.6 mm strip), no supports; glue on the upper-arm block front face |
| `v333_vine_fore_L.stl` | 1 | PLA green | 0.12 | 2 walls, 100% | flat (1.6 mm strip), no supports; glue on the forearm block front face |
| `v333_vine_fore_R.stl` | 1 | PLA green | 0.12 | 2 walls, 100% | flat (1.6 mm strip), no supports; glue on the forearm block front face |
| `v334_kilt_petal_00.stl` | 1 | PLA green (or TPU 95A) | 0.16 | 3 walls, 100% | upside down on the lip (as exported); leaf flares <= ~30 deg from vertical - no supports (brim 3 mm helps the narrow lip) |
| `v334_kilt_petal_01.stl` | 1 | PLA green (or TPU 95A) | 0.16 | 3 walls, 100% | upside down on the lip (as exported); leaf flares <= ~30 deg from vertical - no supports (brim 3 mm helps the narrow lip) |
| `v334_kilt_petal_02.stl` | 1 | PLA green (or TPU 95A) | 0.16 | 3 walls, 100% | upside down on the lip (as exported); leaf flares <= ~30 deg from vertical - no supports (brim 3 mm helps the narrow lip) |
| `v334_kilt_petal_03.stl` | 1 | PLA green (or TPU 95A) | 0.16 | 3 walls, 100% | upside down on the lip (as exported); leaf flares <= ~30 deg from vertical - no supports (brim 3 mm helps the narrow lip) |
| `v334_kilt_petal_04.stl` | 1 | PLA green (or TPU 95A) | 0.16 | 3 walls, 100% | upside down on the lip (as exported); leaf flares <= ~30 deg from vertical - no supports (brim 3 mm helps the narrow lip) |
| `v334_kilt_petal_05.stl` | 1 | PLA green (or TPU 95A) | 0.16 | 3 walls, 100% | upside down on the lip (as exported); leaf flares <= ~30 deg from vertical - no supports (brim 3 mm helps the narrow lip) |
| `v334_kilt_petal_06.stl` | 1 | PLA green (or TPU 95A) | 0.16 | 3 walls, 100% | upside down on the lip (as exported); leaf flares <= ~30 deg from vertical - no supports (brim 3 mm helps the narrow lip) |
| `v334_kilt_petal_07.stl` | 1 | PLA green (or TPU 95A) | 0.16 | 3 walls, 100% | upside down on the lip (as exported); leaf flares <= ~30 deg from vertical - no supports (brim 3 mm helps the narrow lip) |
| `v334_kilt_petal_08.stl` | 1 | PLA green (or TPU 95A) | 0.16 | 3 walls, 100% | upside down on the lip (as exported); leaf flares <= ~30 deg from vertical - no supports (brim 3 mm helps the narrow lip) |
| `v334_kilt_petal_09.stl` | 1 | PLA green (or TPU 95A) | 0.16 | 3 walls, 100% | upside down on the lip (as exported); leaf flares <= ~30 deg from vertical - no supports (brim 3 mm helps the narrow lip) |
| `v332_boot_L/R.stl` | 2 | PETG or TPU 95A black (PLA ok) | 0.2 | 3 walls, 10% | sole down; tree supports (build plate only) under the toe-cap underside |
| `v332_shin_cover_*_L/R.stl` | 4 | PLA wood-brown | 0.2 | 3 walls, 15% | split face down; no supports |
| `v332_chest_vine.stl` | 1 | PLA green | 0.12 | 2 walls, 100% | as exported, tree supports under the curl |
| `v39_upper_arm_L/R.stl` | 2 | PLA **BLACK** (v3.33) | 0.2 | 4 walls, 30% | outer plate face down, no supports |
| `v39_forearm_L/R.stl` | 2 | PLA **BLACK** (v3.33) | 0.2 | 4 walls, 30% | inner face down |
| `v331_kilt_band.stl` | 1 | PLA **GREEN** (v3.33) | 0.2 | 3 walls, 20% | upside down, no supports |
| `v331_torso_shell_front.stl` | 1 | PLA wood-brown (or wood-fill PLA) | 0.2 | 3 walls, 15% gyroid | split face down (as exported); tree supports only inside the two shoulder-boss holes; brim 5 mm |
| `v331_torso_shell_back.stl` | 1 | PLA wood-brown | 0.2 | 3 walls, 15% gyroid | split face down; no supports |
| `v331_torso_frame.stl` | 1 | PLA+/PETG any colour (hidden) | 0.2 | 4 walls, 30% gyroid (load path) | back rail face down (as exported); tree supports under the hip deck, neck cradle and the two strut columns/gussets |
| `v39_hip_cradle.stl` | 1 | PLA/PETG any (hidden) | 0.2 | 4 walls, 30% | flipped, seats up; supports under the T-arms |
| `v39_hip_bracket_L/R.stl` | 2 | PETG or PLA+ black | 0.2 | 5 walls, 40% (load path) | as exported (sleeve axis vertical); supports under the webs |
| `v39_thigh_sheet_a.stl` | 2 | PLA **BLACK** (v3.32 recolour; was wood-brown) | 0.2 | 4 walls, 40% | flat |
| `v331_thigh_sheet_b.stl` | 2 | PLA **BLACK** (v3.32 recolour; was wood-brown) | 0.2 | 4 walls, 40% | flat |
| `v39_thigh_spacer.stl` | 2 | PLA black | 0.2 | 4 walls, 40% | flat |
| `v39_boot_cuff.stl` | 2 | PLA black | 0.2 | 3 walls, 15% | upright ring, no supports |
| `v39_leaf_M.stl` | 1 | PLA green | 0.12 | 100% | veined face down, peg up |
| `v39_leaf_S.stl` | 2 | PLA green | 0.12 | 100% | veined face down, peg up |
Colour summary:
- **BLACK:** gripper_housing, finger_moving, upper_arm, forearm, boots, boot_cuff, thigh_spacer, hip_bracket, thigh_sheet_a/b
- **WOOD-BROWN:** shoulder/elbow sleeves, torso shells, shin covers
- **GREEN:** kilt petals, kilt_band, leaves, vines, chest vine
- **Any colour (hidden):** torso_frame, hip_cradle

Totals (rough): section A (arms and kilt) is about 271 g and 30 h. Section B is about 400 g and 34 h.

### Twiglet: head v3.30 (`print/mods/Twiglet/head_v3.30/`)

This table comes from [print_note_head_v330.md](../print/mods/Twiglet/head_v3.30/print_note_head_v330.md). The PETG is wood-brown, printed at 240–250 °C on a 70–80 °C bed (textured PEI with glue stick, part fan 30–50 %).

| File | Qty | Material / colour | Layer | Walls / infill | Orientation / supports |
|---|---|---|---|---|---|
| `v330_head_head_upper.stl` | 1 | PETG wood-brown | 0.16 | 2 walls (0.8 mm) + 3 top/3 bottom, **8 % gyroid**; modifier 4 walls / 40 % on the M3 insert bosses only | split-plane rim down (dome up); tree supports INSIDE only (crown) + the eye bores' top edge |
| `v330_head_head_lower.stl` | 1 | PETG wood-brown | 0.16 | as head_upper | split-plane rim down; tree supports inside the eye bores' upper edges |
| `v330_head_snout.stl` | 1 | PETG wood-brown | 0.2 (0.16 makes the grain pop) | 2 walls, **8 % gyroid** | mouth face down; no supports |
| `v330_head_chin_collar_L/R.stl` | 1 + 1 | PETG wood-brown | 0.16 | as head_upper | as exported (flat top face on the bed); no supports |
| `v330_head_eye_bezel_L/R.stl` | 1 + 1 | matte BLACK PLA | 0.16 | 2 walls, 8 % | front ring face down (textured PEI for a matte front); no supports |
| `v330_head_display_carrier_L/R.stl` | 1 + 1 | black PLA | 0.2 | 2 walls, 8 %; modifier 4 walls on the M3 holes | ring back face on the bed; no supports |
| `v330_head_head_yaw_to_roll.stl` | 1 | PLA+ / PETG (structural, hidden) | 0.2 | 4 walls, 40 % | yaw ring face on the bed; supports from the build plate under the rear frame and the roll hub |

`head_upper` (15.6 MB) and `head_lower` (20.0 MB) are the largest STLs in the repo. Both are under 25 MB.

### Twiglet: wig v3.44 (`print/mods/Twiglet/wig_v3.44/`)

| File | Qty | Material / colour | Layer | Walls / infill | Orientation / supports |
|---|---|---|---|---|---|
| `FINAL_WIG.stl` | 1 | yellow / blond matte PLA | 0.2 | 2 walls (0.8 mm), 3 top/3 bottom, **4.5 % LIGHTNING (required, the sims assume it)** | as exported (crown axis tilted 38°, the least-support of 6120 orientations searched); tree supports (auto, build plate only, 40° threshold, 0.2 mm top Z gap) + 5 mm brim |

- 186.2 g; size 243.1 × 246.4 × 239.9 mm (fits the P1S); ~473 cm³ support, 212 cm² overhang. Closed crown; walls ≥ 2.39 mm.
- Print `FINAL_WIG.stl`, not `FINAL_WIG_model_frame.stl` (that one is the same mesh in the head model frame, for the sims).
- A "4 %" infill figure was mentioned, but the records only show 4.5 % LIGHTNING. Use 4.5 %.

### Not printed
- Felt hat: fabric.
- Ballast: 25 g of steel.
- Wig pins: 3 mm rods.
- See [BOM.md](BOM.md).

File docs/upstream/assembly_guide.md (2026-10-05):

# Assembly guide

> Before assembling the duck, you should first [configure your motors](./configure_motors.md)

## Requirements : 

You will need : 
- A soldering iron, and basic electronics tools and skills
- X m3 screws (TODO : add the exact number)
- Some wire
- Loctite Threadlocker blue 243

> General note : Everytime you screw something in the motors metal against metal, you want to use a little loctite threadlocker. This will prevent the screws from coming loose due to the vibrations during the operation of the robot. It adds a little time to to the build, but you'll be glad you took the time ;)
>
> Don't use loctite with the plastic screws

> At any time, you can refer to the CAD here : https://cad.onshape.com/documents/64074dfcfa379b37d8a47762/w/3650ab4221e215a4f65eb7fe/e/0505c262d882183a25049d05

## Steps :

### Assemble the trunk

Place the bearings in `trunk_bottom` like so, and insert M3 inserts in these holes. It's also a good time to insert the 4 M3 inserts in the bottom of this part to mount body parts later on.



Then assamble `trunk_bottom` and `trunk_top`, and screw them together with 2 `M3x10` screws through these holes



Mount the middle motor like so and screw it with the plastic screws that came with the motors : 



Insert `roll_motor_bottom` like this 



### Assemble the feet

Both feet are the same. 

First, assemble `foot_bottom_tpu` with `foot_bottom_pla`. Insert M3 inserts in these holes :



And screw the two parts together with two `M3x6` screws.

Then, insert M3 inserts in these holes in `foot_top` here : 



And assemble everything like so. Make sure the driver side of the motor is on the `foot_top` part side : 

<table>
  <tr>
    <td>  </td>
    <td>  </td>
   </tr> 
</table>

You can add the foot switches like this too :

> You press fit them so that the switch is activated when the foot touches the ground

<table>
  <tr>
    <td>  </td>
    <td>  </td>
   </tr> 
</table>

### Assemble the shins

Insert M3 Inserts in these holes of `leg_spacer` (on both sides. Insert 4 M3 inserts in total) :



Then, first plug the motor cable in the foot's motor, and make it go through the `right_sheet` like so 



Then assemble like below:



### Assemble the thighs 

The thigh is pretty much the same thing, except the `hip_pitch` motor is mounted this way (important for the zero position)



### Assemble the hips

Mount `left_roll_to_pitch` or `right_roll_to_pitch`, here the parts are symmetrical so you have to use the right one.



Mount `roll_motor_top` to the `hip_yaw` servo (screw from the bottom). Don't mount the servo to the trunk yet.



Then mount `hip_roll` like this 



And insert the sub assembly like this 



Screw everything you can (with the plastic screws provided with the servos)

You can now mount the leg like this :



And do the same for the other leg :)

Your duck should now look like this 



### Assemble the neck

You know the drill



### Assemble the head mechanism

First, mount `head_pitch_to_yaw` like this 



Then, independently mount `head_yaw_to_roll` and `head_roll_mount` to `head_roll dof`



(You can insert `head_bot_plate` and `body_middle_top` now too to avoid having to disassamble the head later)

Then 



Then 



Your duck should now look like this 



### Mount the servo driver board

TODO take a photo

### Mount the IMU

Like this 

> It's actually better to mount the IMU with the correct natural orientation, which would be flipped along the X axis compared to the pictures below
> In the picture below, the IMU is mounted upside down.
> It probably doesn't really matter a lot if you mount it upside down or not. You can configure how you mounted it later

<table>
  <tr>
    <td> </td>
    <td> </td>
   </tr> 
</table>

## Electronics

Here is the global electonics schematic for reference 

<table>
  <tr>
    <td> </td>
    <td> </td>
   </tr> 
</table>

Here is how to wire the feet 

feet

Here is the pin mapping on the Pi Zero header

| **LEDs** | **Pi Zero Header Pin** | **Pi Zero Function** |
|:---:|:---:|:---:|
|  Left Eye Anode (+) | 16 | GPIO 23 |
| Right Eye Anode (+) | 18 | GPIO 24 |
| Projector Anode (+) | 22 | GPIO 25 |
|  Common Cathode (-) | 6 | GND |
| | | |
| **Antennas** | | |
| Left PWM | 32 | GPIO 12 (PWM) |
| Right PWM | 33 | GPIO 13 (PWM) |
| 5V | 2 | 5V |
| GND | 6 | GND |
| | | |
|  **Foot Switches**  | | |
| Left Foot | 15 | GPIO 22 |
| Right Foot | 13 | GPIO 27 |
| GND | 9 | GND |
| | | |
| **BNO055** | | |
| VIN | 1 | 3V3 |
| 3VO | NC | - |
| GND | 9 | GND |
| SDA | 3 | GPIO 2 |
| SCL | 5 | GPIO 3 |
| RST | NC | - |
| | | |
| **MAX98357A** | | |
| LRC | 35 | GPIO 19 |
| BCLK | 12 | GPIO 18 |
| DIN | 40 | GPIO 21 |
| GAIN | NC | - |
| SD | NC | - |
| GND | 6 | GND |
| VIN | 2 | 5V |

### Battery pack

> To be safe, make sure your cells are charged to the same voltage before placing them in the holder.

<table>
  <tr>
    <td> </td>
    <td> </td>
   </tr> 
</table>

### Head

First, insert the M3 inserts in all these holes 



> TODO add instructions for expression features (camera, antennas, eye leds, projector and speaker)

Then insert the bearing, mount the ear motors and the raspberry pi zero 2w.

For reference, the inside of the head looks like this now 



Then assemble the neck with the head like this



## Body

First screw on `body_middle_bottom`

Capture d’écran du 2025-02-09 12-10-00

Then insert the M3 inserts in all the holes of `body_middle_bottom` and `body_middle_top` on which we'll mount the battery pack and `body_front`.

Then mount `body_middle_top`, `body_front` and the battery pack

<table>
  <tr>
    <td> </td>
    <td> </td>
   </tr> 
</table>

Et voila :) 

<table>
  <tr>
    <td> </td>
    <td> </td>
   </tr> 
</table>

> Now that your duck is fully assembled, you setup the raspberry pi and the runtime software [here](https://github.com/apirrone/Open_Duck_Mini_Runtime)

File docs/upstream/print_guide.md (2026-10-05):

# Print guide

You can find the `.stl` files under the `print/` directory at the root of this repo. 

All the parts are printed in standard PLA with 15% infill, except for `foot_bottom_tpu.stl`, which is to be printed in TPU at 40% infill.

## Parts to print
- foot_top.stl x2
- foot_side.stl x2
- foot_bottom_pla.stl x2
- foot_bottom_tpu.stl x2 (TPU)
- knee_to_ankle_left_sheet.stl x4
- knee_to_ankle_right_sheet.stl x4
- leg_spacer.stl x4
- left_roll_to_pitch.stl x1
- right_roll_to_pitch.stl x1
- roll_motor_bottom.stl x2
- roll_motor_top.stl x2
- trunk_bottom.stl x1
- trunk_top.stl x1
- neck_left_sheet.stl x1
- neck_right_sheet.stl x1
- head_pitch_to_yaw.stl x1
- head_yaw_to_roll.stl x1
- head_roll_mount.stl x1
- head.stl x1
- head_bot_sheet.stl x1
- left_antenna_holder.stl x1
- right_antenna_holder.stl x1
- left_cache.stl x1
- right_cache.stl x1
- body_front.stl x1
- body_middle_bottom.stl x1
- body_middle_top.stl x1
- body_back.stl x1
- battery_pack_lid.stl x1
- bulb.stl x1
- flash_light_module.stl x1
- flash_reflector_interface.stl x1
- left_eye.stl x1
- right_eye.stl x1
- speaker_interface.stl x1
- speaker_stand.stl x1

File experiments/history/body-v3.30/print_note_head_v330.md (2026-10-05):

# Twiglet head v3.30 - print note (Blender-modelled one-piece wig + re-aimed snout + lowered, rounder eyes; wig attachment unchanged from v3.16)

| file | size (mm) | fits P1S | est. g (+support) | h | >45 deg overhang cm2 |
|---|---|---|---|---|---|
| v330_head_wig.stl | 244.9 x 240.0 x 242.8 | yes | 187 (+51) | 14.8 | 142.3 |
| v330_head_snout.stl | 71.6 x 71.6 x 101.5 | yes | 54 (+5) | 3.7 | 12.1 |
| v330_head_head_upper.stl | 207.9 x 207.9 x 90.3 | yes | 143 (+14) | 9.8 | 197.6 |
| v330_head_head_lower.stl | 209.0 x 210.0 x 72.9 | yes | 177 (+18) | 12.2 | 347.6 |
| v330_head_eye_bezel_L.stl | 70.8 x 70.8 x 6.3 | yes | 5 (+0) | 0.3 | 0.8 |
| v330_head_eye_bezel_R.stl | 70.8 x 70.8 x 6.3 | yes | 5 (+0) | 0.3 | 0.8 |
| v330_head_display_carrier_L.stl | 71.2 x 71.2 x 24.8 | yes | 9 (+1) | 0.6 | 5.9 |
| v330_head_display_carrier_R.stl | 71.2 x 71.2 x 24.8 | yes | 9 (+1) | 0.6 | 5.9 |
| v330_head_chin_collar_L.stl | 55.2 x 79.8 x 13.6 | yes | 4 (+0) | 0.3 | 0.1 |
| v330_head_chin_collar_R.stl | 55.3 x 79.8 x 13.6 | yes | 4 (+0) | 0.3 | 0.1 |
| v330_head_head_yaw_to_roll.stl | 77.2 x 80.0 x 42.2 | yes | 20 (+2) | 1.4 | 10.1 |

## Print list (vs v3.29)
- NOTHING HAS BEEN PRINTED YET, so print the full head set. CHANGED in v3.30 (all in this zip): wig (Blender locks), snout (re-aimed, mouth raised), head_upper + head_lower (eye openings 4 mm lower, wider wood rim, carrier posts shortened), eye_bezel_L/R (round, smaller ring), display_carrier_L/R (same shape, re-exported at the new height), head_lower + chin_collar_L/R + head_yaw_to_roll (HEAD-RANGE REDESIGN: roll-bearing holder moved forward, collar tabs -> internal insert bosses, collars cut to the front band, neck part rear re-cut - see 'Head-range redesign' below). head_yaw_to_roll is a NECK MECHANICS part: print this one INSTEAD of v39_head_yaw_to_roll from the body pack.
- Head range on the v3.31 rev C body (whole printed head vs torso shells / frame / leaves / kilt / arms at rest, 315-pose grid pitch +-45 / yaw +-160 / roll +-30): whole head 221 -> 153 of 315 grid poses with any contact (exact meshes, arms at rest; v3.30a trimmed collars -> head-range redesign); clean range from level at yaw 0: back pitch +9 -> +26 deg (now limited by the roll bearing itself vs the back torso shell; printed head alone +30), roll +-15 -> +-18 deg (head_lower side shell vs upper arms), forward pitch -36 (neck yaw ring vs front torso shell, unchanged), yaw +-160; at yaw != 0 back pitch +18-19 (neck yaw-ring sides, unchanged).

## Head-range redesign (v3.30) - assembly
- Roll bearing: the same 20x32x7 bearing, now pressed into the new head_lower housing (12.1 mm further forward on the same roll axis; the bearing outer ring shows through the housing's bottom window - that is intended, 282 deg wrap + rear lip hold it). The new head_yaw_to_roll hub slides 7 mm into it exactly as before; assembly order as the ODM guide.
- Chin collars: press 4 x M3 x 5 x 4 mm heat-set inserts (vertical, from below) into the 4 bosses inside the head_lower rim; each collar's 2 inner ledges then take 2 x M3 x 8 screws from below up into them (4 screws total). The old 4 radial collar screws / external tabs are gone.
- BALLAST (required, 25 g steel): moving the bearing forward and removing the rear strut / tabs moved the head COM forward (head-pitch hold would drop to 1.9x). Epoxy 25 g of steel on the new ledge inside the back of head_lower, against the shell, centred on the rear centreline within +-30 deg (e.g. 5 x M8 hex nuts standing on edge, or 5 x 5 g adhesive wheel-balance weights cut to <= 14 mm tall). Weigh it: 23-27 g. The sims include exactly this.
- Range achieved (exact, rev C body, arms at rest): back pitch at yaw 0 +26 deg (was +9/+10; now limited by the roll bearing itself touching the back torso shell - the printed head alone clears +30), roll at yaw 0 +-18 deg (was +-15; limited by the head_lower side shell vs the upper arms - more would cut the visible ball sides), forward pitch -36 (neck ring vs front torso shell, unchanged), back pitch at yaw != 0 +18-19 (neck yaw-ring sides, unchanged).
- The head-half joint (4 M3 screws into heat-set inserts), head_upper pin holes + key groove and the snout socket are unchanged. The kilt is a separate pack (twiglet-kilt-v3.16-stl.zip, unchanged).
- Sim basis (v3.30 on the v3.31 rev C body): every head part is simulated at 2 walls (0.8 mm) + 8 % infill (wig 4.5 % lightning); head_upper / head_lower / snout / chin collars at PETG 1.27 g/cm3, the rest PLA 1.24. Print exactly these settings (heavier shells move the head COM forward and up).
- Materials: head_upper, head_lower, snout, chin collars = wood-brown PETG; wig = yellow / blond PLA (lightning infill, tree supports); eye bezels + display carriers = matte black PLA.

## Per-part orientation / supports / infill

| part | material | orientation (as exported) | supports | settings / infill |
|---|---|---|---|---|
| v330_head_wig.stl | yellow / blond matte PLA | as exported: crown axis tilted 56 deg from straight-down (least support volume of 6120 orientations searched); lies on the dome + clump backs | tree supports (auto, build plate only, threshold 40 deg, 0.2 mm top Z gap) + 5 mm brim | 0.2 mm layers, 2 walls (0.8 mm), 3 top / 3 bottom layers, sparse infill 4.5 % LIGHTNING - REQUIRED: the sims assume this wig at 4.5 % (simC/sweepR2.txt (v3.31 rev C body, head-range redesign incl. 25 g rear ballast, PETG head shells): margin 33.5 / 33.5 / 33.3 / 33.1 / 32.1 mm at 0 / 2 / 3 / 4.5 / 6 % wig infill; 4.5 % stays the required value (>= 32 mm everywhere, head-pitch hold 2.10x at 4.5 %).), so print exactly that |
| v330_head_snout.stl | wood brown PETG | as exported: mouth face DOWN on the bed (flat rim annulus), spigot + key tab up | none needed (the root plug / spigot are bridged by the cone) | brown PETG (240-250 C, bed 70-80 C): 0.2 mm layers (0.16 mm makes the grain pop), 2 walls (0.8 mm), 8 % gyroid - the sims assume 8 % |
| v330_head_head_upper.stl | wood brown PETG | split-plane rim down (dome up) | tree supports INSIDE only (crown above ~60 deg, hidden under the hat) + the two eye bores' top edge | brown PETG: 0.16 mm layers, 2 walls (0.8 mm) + 3 top / 3 bottom, 8 % gyroid - the sims assume exactly this at 1.27 g/cm3 (3 walls / 15 % would add ~130 g to the head and break the head-pitch and balance margins); slicer modifier (4 walls, 40 %) only on the M3 heat-set insert bosses / screw holes (~2 g); 240-250 C nozzle / 70-80 C bed, textured PEI (glue stick as release), part fan 30-50 % |
| v330_head_head_lower.stl | wood brown PETG | split-plane rim down | tree supports inside the eye bores' upper edges, as before | brown PETG: 0.16 mm layers, 2 walls (0.8 mm) + 3 top / 3 bottom, 8 % gyroid - the sims assume exactly this at 1.27 g/cm3 (3 walls / 15 % would add ~130 g to the head and break the head-pitch and balance margins); slicer modifier (4 walls, 40 %) only on the M3 heat-set insert bosses / screw holes (~2 g); 240-250 C nozzle / 70-80 C bed, textured PEI (glue stick as release), part fan 30-50 % |
| v330_head_eye_bezel_L.stl | matte BLACK PLA | front ring face DOWN on the bed (spigot up) | none | 0.16 mm, 2 walls (0.8 mm), 8 % infill (the sims assume this), textured PEI for a matte front |
| v330_head_eye_bezel_R.stl | matte BLACK PLA | front ring face DOWN on the bed (spigot up) | none | 0.16 mm, 2 walls (0.8 mm), 8 % infill (the sims assume this), textured PEI for a matte front |
| v330_head_display_carrier_L.stl | black PLA | ring back face on the bed | none | 0.2 mm, 2 walls (0.8 mm), 8 % infill (the sims assume this); modifier 4 walls on the M3 screw holes |
| v330_head_display_carrier_R.stl | black PLA | ring back face on the bed | none | 0.2 mm, 2 walls (0.8 mm), 8 % infill (the sims assume this); modifier 4 walls on the M3 screw holes |
| v330_head_chin_collar_L.stl | wood brown PETG | as exported (collar flipped, flat top face on the bed) | none | brown PETG: 0.16 mm layers, 2 walls (0.8 mm) + 3 top / 3 bottom, 8 % gyroid - the sims assume exactly this at 1.27 g/cm3 (3 walls / 15 % would add ~130 g to the head and break the head-pitch and balance margins); slicer modifier (4 walls, 40 %) only on the M3 heat-set insert bosses / screw holes (~2 g); 240-250 C nozzle / 70-80 C bed, textured PEI (glue stick as release), part fan 30-50 % |
| v330_head_chin_collar_R.stl | wood brown PETG | as exported (collar flipped, flat top face on the bed) | none | brown PETG: 0.16 mm layers, 2 walls (0.8 mm) + 3 top / 3 bottom, 8 % gyroid - the sims assume exactly this at 1.27 g/cm3 (3 walls / 15 % would add ~130 g to the head and break the head-pitch and balance margins); slicer modifier (4 walls, 40 %) only on the M3 heat-set insert bosses / screw holes (~2 g); 240-250 C nozzle / 70-80 C bed, textured PEI (glue stick as release), part fan 30-50 % |
| v330_head_head_yaw_to_roll.stl | PLA+ / PETG (structural, hidden) | as exported (= v39_head_yaw_to_roll print orientation: yaw ring face on the bed) | supports from the build plate under the new rear frame (cross-bar / side arms 6.75 mm above the bed) and under the roll hub | 0.2 mm, 4 walls, 40 % infill (as the ODM guide for the neck parts) |

## Mesh gate (every STL re-loaded from disk: open edges / non-manifold edges / bodies / volume)

| part | open edges | non-manifold edges | bodies | watertight | volume cm3 | faces |
|---|---|---|---|---|---|---|
| wig | 0 | 0 | 1 | True | 721.02 | 56390 |
| snout | 0 | 0 | 1 | True | 185.29 | 40246 |
| head_upper | 0 | 0 | 1 | True | 137.52 | 311722 |
| head_lower | 0 | 0 | 1 | True | 233.31 | 400612 |
| eye_bezel_L | 0 | 0 | 1 | True | 5.36 | 3072 |
| display_carrier_L | 0 | 0 | 1 | True | 14.28 | 4292 |
| eye_bezel_R | 0 | 0 | 1 | True | 5.36 | 3072 |
| display_carrier_R | 0 | 0 | 1 | True | 14.34 | 4246 |
| chin_collar_L | 0 | 0 | 1 | True | 4.23 | 10220 |
| chin_collar_R | 0 | 0 | 1 | True | 4.23 | 9984 |
| head_yaw_to_roll | 0 | 0 | 1 | True | 23.63 | 7010 |

## Snout (v3.30) - wood brown PETG
- v3.30 re-aim: yaw -4 / pitch +22 deg (v3.29 -12 / -6): mouth raised to the photos; modelled in Blender 4.5 (3 mm root fillet, wood-grain grooves); same keyed spigot into the unchanged head_lower socket. Orientation: as exported: mouth face DOWN on the bed (flat rim annulus), spigot + key tab up. Supports: none needed (the root plug / spigot are bridged by the cone). Settings: brown PETG (240-250 C, bed 70-80 C): 0.2 mm layers (0.16 mm makes the grain pop), 2 walls (0.8 mm), 8 % gyroid - the sims assume 8 %. ~54 g, ~3.7 h.
- Fit: dry-fit so the key tab sits in the head_lower key slot and the root lies flush on the ball, then glue (CA or epoxy). The root top is trimmed inside the head-split lift cylinder, so head_upper still lifts straight off with the snout glued in.

## Wig - one piece, yellow / blond matte PLA
- Orientation: as exported: crown axis tilted 56 deg from straight-down (least support volume of 6120 orientations searched); lies on the dome + clump backs. Supports: tree supports (auto, build plate only, threshold 40 deg, 0.2 mm top Z gap) + 5 mm brim. ~51 g of tree support, ~14.8 h (P1S standard).
- Settings: 0.2 mm layers, 2 walls (0.8 mm), 3 top / 3 bottom layers, sparse infill 4.5 % LIGHTNING - REQUIRED: the sims assume this wig at 4.5 % (simC/sweepR2.txt (v3.31 rev C body, head-range redesign incl. 25 g rear ballast, PETG head shells): margin 33.5 / 33.5 / 33.3 / 33.1 / 32.1 mm at 0 / 2 / 3 / 4.5 / 6 % wig infill; 4.5 % stays the required value (>= 32 mm everywhere, head-pitch hold 2.10x at 4.5 %).), so print exactly that. Sharp lock points: 5 mm brim, 'thick bridges' off.
- File size: the wig STL is the Blender-decimated mesh (blender/decimate_v330.py, COLLAPSE) of the simulated wig, re-gated closed/manifold; 564k -> 56k faces (ratio 0.10), surface deviation p99 0.02 mm / max 0.06 mm, volume 721.06 -> 721.02 cm3.
- Shape (v3.30, MODELLED IN BLENDER - smooth sleek locks): every lock is a Bezier spine (v3.29 lock layout) lofted with a smooth rounded section on a 2 mm side wall, Catmull-Clark subdivided, all locks unioned by a 0.7 mm voxel remesh and Taubin-smoothed in Blender (blender/build_wig_v330.py, wig_v330.blend) -> clean continuous lock outlines (no stair-stepped / serrated edges, no felt grooves, no V-notches), locks blend into each other with soft partings; central fringe triangle, soft sideburns and temple flicks kept. Seat / crown / hat band / pins / key unchanged (procedural, hair_v330.wig_blend).
- Felt hat (NOT printed - your fabric hat): pull it on so its edge sits in the recessed band all the way round (front edge just above the fringe roots, down over the left ear, tail flopping to the robot's left). The green hat in the renders is a render proxy of that fabric hat.
- No fly-away blades any more (v3.30): the lower side-lock ends still overhang - let the slicer's tree supports (auto) reach them. Handle the printed wig by the crown.

## Attachment (the wig cannot rotate, slide or lift)
- Locate: 4 x 3 mm steel or PLA-filament rods, 12 mm long: glue 5 mm into the 4 blind holes (5 mm deep, v3.30; was 6.5) in the wig; the 7 mm ends drop into the 4 vertical 3.2 mm holes (7.5 mm deep) in head_upper. All pins are vertical = parallel to the push-on direction (no binding).
- Key: a 2.4 mm wide x 1.1 mm tongue (4 arcs of 70/40/40/40 deg - the long arc at the front, so it only fits one way) on the wig underside sits in the matching 3.0 x 1.0 mm groove in head_upper (0.3 mm side / 0.2 mm bottom glue gap). Groove floor wall 1.47 mm.
- Glue land: the whole wig underside is a seat with a controlled 0.3 mm gap to the head (p5/p50 0.333/0.45 mm); the lower lock ends lift off the head (flare) and are not glued.
- Glue: 2-part epoxy (5-min or 30-min, e.g. Loctite/Araldite) - thin bead on the crown seat band + tongue + pin holes, push down, tape for 1 h. Medium CA also works but is brittle on impact; epoxy fills the 0.2-0.3 mm gap properly. For a removable wig: pins + tongue + 3 dots of E6000 / hot glue.

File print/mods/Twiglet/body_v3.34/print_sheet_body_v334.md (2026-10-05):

# Twiglet body v3.34 - full print sheet (all non-head body parts; every STL is in this zip under stl/)

Printer: Bambu P1S with a 0.4 mm nozzle (all parts fit 256 x 256 x 256). Grams and hours are rough formula estimates (no slicer run), so slice to confirm. Every file is in its print orientation, and z = 0 is the bed.

## A. Arm + kilt parts (v3.34 changed: gripper_housing_L/R and all 10 kilt petals; the rest are the v3.33 files, unchanged)
| Part | File | Qty | Material | Orientation / supports | Walls / infill | Layer mm | solid cm3 | est g | est h | Verdict |
|---|---|---|---|---|---|---|---|---|---|---|
| shoulder_sleeve_L | v333_shoulder_sleeve_L.stl | 1 | PLA wood-brown (wood-fill ok) | outer cap face down (as exported); tree supports inside the open bottom / servo pocket | 4 walls, 30% | 0.2 | 9.40 | 11.1 | 0.92 | READY (unchanged v3.33) |
| shoulder_sleeve_R | v333_shoulder_sleeve_R.stl | 1 | PLA wood-brown (wood-fill ok) | outer cap face down (as exported); tree supports inside the open bottom / servo pocket | 4 walls, 30% | 0.2 | 9.40 | 11.1 | 0.92 | READY (unchanged v3.33) |
| elbow_sleeve_L | v333_elbow_sleeve_L.stl | 1 | PLA wood-brown (wood-fill ok) | outer cap face down (as exported); tree supports inside the skirt / servo pocket | 4 walls, 30% | 0.2 | 10.67 | 12.6 | 1.05 | READY (unchanged v3.33) |
| elbow_sleeve_R | v333_elbow_sleeve_R.stl | 1 | PLA wood-brown (wood-fill ok) | outer cap face down (as exported); tree supports inside the skirt / servo pocket | 4 walls, 30% | 0.2 | 10.66 | 12.6 | 1.05 | READY (unchanged v3.33) |
| gripper_housing_L | v334_gripper_housing_L.stl | 1 | PLA/PETG black | box inner (body-side) face down (as exported, lay-flat); supports under the prong slot + finger opening | 4 walls, 30% | 0.2 | 41.72 | 49.1 | 4.10 | READY (CHANGED v3.34: bigger hollow FEETECH box) |
| gripper_housing_R | v334_gripper_housing_R.stl | 1 | PLA/PETG black | box inner (body-side) face down (as exported, lay-flat); supports under the prong slot + finger opening | 4 walls, 30% | 0.2 | 41.72 | 49.1 | 4.10 | READY (CHANGED v3.34: bigger hollow FEETECH box) |
| finger_moving_L | v333_finger_moving_L.stl | 1 | PLA/PETG black | flat side down (as exported, lay-flat); no supports | 4 walls, 100% | 0.16 | 4.70 | 5.8 | 0.83 | READY (unchanged v3.33) |
| finger_moving_R | v333_finger_moving_R.stl | 1 | PLA/PETG black | flat side down (as exported, lay-flat); no supports | 4 walls, 100% | 0.16 | 4.70 | 5.8 | 0.83 | READY (unchanged v3.33) |
| leaf_shoulder_L | v333_leaf_shoulder_L.stl | 1 | PLA green (or TPU 95A) | back face down; tree supports under the curled tip | 2 walls, 100% | 0.12 | 0.48 | 0.6 | 0.08 | READY (unchanged v3.33) |
| leaf_shoulder_R | v333_leaf_shoulder_R.stl | 1 | PLA green (or TPU 95A) | back face down; tree supports under the curled tip | 2 walls, 100% | 0.12 | 0.48 | 0.6 | 0.08 | READY (unchanged v3.33) |
| leaf_elbow_L | v333_leaf_elbow_L.stl | 1 | PLA green (or TPU 95A) | back face down; tree supports under the curled tip | 2 walls, 100% | 0.12 | 0.36 | 0.4 | 0.06 | READY (unchanged v3.33) |
| leaf_elbow_R | v333_leaf_elbow_R.stl | 1 | PLA green (or TPU 95A) | back face down; tree supports under the curled tip | 2 walls, 100% | 0.12 | 0.36 | 0.4 | 0.06 | READY (unchanged v3.33) |
| vine_upper_L | v333_vine_upper_L.stl | 1 | PLA green | flat (1.6 mm strip), no supports; glue on the upper-arm block front face | 2 walls, 100% | 0.12 | 0.22 | 0.3 | 0.04 | READY (unchanged v3.33) |
| vine_upper_R | v333_vine_upper_R.stl | 1 | PLA green | flat (1.6 mm strip), no supports; glue on the upper-arm block front face | 2 walls, 100% | 0.12 | 0.22 | 0.3 | 0.04 | READY (unchanged v3.33) |
| vine_fore_L | v333_vine_fore_L.stl | 1 | PLA green | flat (1.6 mm strip), no supports; glue on the forearm block front face | 2 walls, 100% | 0.12 | 0.23 | 0.3 | 0.04 | READY (unchanged v3.33) |
| vine_fore_R | v333_vine_fore_R.stl | 1 | PLA green | flat (1.6 mm strip), no supports; glue on the forearm block front face | 2 walls, 100% | 0.12 | 0.26 | 0.3 | 0.05 | READY (unchanged v3.33) |
| kilt_petal_00 | v334_kilt_petal_00.stl | 1 | PLA green (or TPU 95A) | upside down on the lip (as exported); leaf flares <= ~30 deg from vertical - no supports (brim 3 mm helps the narrow lip) | 3 walls, 100% | 0.16 | 9.07 | 11.3 | 1.61 | READY (CHANGED v3.34: wider flared, longer) |
| kilt_petal_01 | v334_kilt_petal_01.stl | 1 | PLA green (or TPU 95A) | upside down on the lip (as exported); leaf flares <= ~30 deg from vertical - no supports (brim 3 mm helps the narrow lip) | 3 walls, 100% | 0.16 | 9.78 | 12.1 | 1.73 | READY (CHANGED v3.34: wider flared, longer) |
| kilt_petal_02 | v334_kilt_petal_02.stl | 1 | PLA green (or TPU 95A) | upside down on the lip (as exported); leaf flares <= ~30 deg from vertical - no supports (brim 3 mm helps the narrow lip) | 3 walls, 100% | 0.16 | 9.07 | 11.2 | 1.61 | READY (CHANGED v3.34: wider flared, longer) |
| kilt_petal_03 | v334_kilt_petal_03.stl | 1 | PLA green (or TPU 95A) | upside down on the lip (as exported); leaf flares <= ~30 deg from vertical - no supports (brim 3 mm helps the narrow lip) | 3 walls, 100% | 0.16 | 7.64 | 9.5 | 1.35 | READY (CHANGED v3.34: wider flared, longer) |
| kilt_petal_04 | v334_kilt_petal_04.stl | 1 | PLA green (or TPU 95A) | upside down on the lip (as exported); leaf flares <= ~30 deg from vertical - no supports (brim 3 mm helps the narrow lip) | 3 walls, 100% | 0.16 | 9.24 | 11.5 | 1.64 | READY (CHANGED v3.34: wider flared, longer) |
| kilt_petal_05 | v334_kilt_petal_05.stl | 1 | PLA green (or TPU 95A) | upside down on the lip (as exported); leaf flares <= ~30 deg from vertical - no supports (brim 3 mm helps the narrow lip) | 3 walls, 100% | 0.16 | 9.30 | 11.5 | 1.65 | READY (CHANGED v3.34: wider flared, longer) |
| kilt_petal_06 | v334_kilt_petal_06.stl | 1 | PLA green (or TPU 95A) | upside down on the lip (as exported); leaf flares <= ~30 deg from vertical - no supports (brim 3 mm helps the narrow lip) | 3 walls, 100% | 0.16 | 9.30 | 11.5 | 1.65 | READY (CHANGED v3.34: wider flared, longer) |
| kilt_petal_07 | v334_kilt_petal_07.stl | 1 | PLA green (or TPU 95A) | upside down on the lip (as exported); leaf flares <= ~30 deg from vertical - no supports (brim 3 mm helps the narrow lip) | 3 walls, 100% | 0.16 | 9.30 | 11.5 | 1.65 | READY (CHANGED v3.34: wider flared, longer) |
| kilt_petal_08 | v334_kilt_petal_08.stl | 1 | PLA green (or TPU 95A) | upside down on the lip (as exported); leaf flares <= ~30 deg from vertical - no supports (brim 3 mm helps the narrow lip) | 3 walls, 100% | 0.16 | 9.24 | 11.5 | 1.64 | READY (CHANGED v3.34: wider flared, longer) |
| kilt_petal_09 | v334_kilt_petal_09.stl | 1 | PLA green (or TPU 95A) | upside down on the lip (as exported); leaf flares <= ~30 deg from vertical - no supports (brim 3 mm helps the narrow lip) | 3 walls, 100% | 0.16 | 7.64 | 9.5 | 1.35 | READY (CHANGED v3.34: wider flared, longer) |

Section A total: 26 prints, about 271 g and 30.1 h of printer time (rough).

## A2. Colour-only changes (rev C geometry, files unchanged)
| Part | File | Qty | Change |
|---|---|---|---|
| upper_arm_L/R | v39_upper_arm_L/R.stl | 2 | print **BLACK** (was wood-brown): the photo shows black brackets/joints between the wood blocks |
| forearm_L/R | v39_forearm_L/R.stl | 2 | print **BLACK** (was wood-brown): the short black wrist collar below the forearm block |
| kilt_band | v331_kilt_band.stl | 1 | print **GREEN** (was wood-brown): felt-green band on top of the kilt like the photo |

Assembly note v3.34: the kilt petals are longer (front 00-02 to the v3.33 hem height, sides/back 6 mm lower) and flare further out; same lip/band fit as v3.33. The gripper box is a thin-wall (1.6 mm) open-bottom shell, 36 x 47 x 57 mm: slide it over the gripper servo exactly like v3.33.

## B. Unchanged parts (rev C / v3.32 (files copied from the rev C pack; settings as in rev C, thigh sheets black as v3.32)
| Part | File | Qty | Material / colour | Orientation / supports | Walls / infill | Layer mm | est g each | est h each | Verdict |
|---|---|---|---|---|---|---|---|---|---|
| boot_L/R | v332_boot_L/R.stl | 2 | PETG or TPU 95A black (PLA ok) | sole down; tree supports (build plate only) under the toe-cap underside | 3 walls, 10% | 0.2 | 67.0 | 5.58 | READY (v3.32) |
| shin_cover_front/back_L/R | v332_shin_cover_*_L/R.stl | 4 | PLA wood-brown | split face down; no supports | 3 walls, 15% | 0.2 | 8.1 | 0.67 | READY (v3.32) |
| chest_vine | v332_chest_vine.stl | 1 | PLA green | as exported, tree supports under the curl | 2 walls, 100% | 0.12 | 0.2 | 0.03 | READY (v3.32) |
| upper_arm_L/R | v39_upper_arm_L.stl | 2 | PLA **BLACK** (v3.33) | outer plate face down, no supports | 4 walls, 30% | 0.2 | 3.0 | 0.36 | READY |
| forearm_L/R | v39_forearm_L.stl | 2 | PLA **BLACK** (v3.33) | inner face down | 4 walls, 30% | 0.2 | 6.8 | 0.64 | READY |
| kilt_band | v331_kilt_band.stl | 1 | PLA **GREEN** (v3.33) | upside down, no supports | 3 walls, 20% | 0.2 | 8.5 | 0.75 | READY |
| torso_shell_front | v331_torso_shell_front.stl | 1 | PLA wood-brown (or wood-fill PLA) | split face down (as exported); tree supports only inside the two shoulder-boss holes; brim 5 mm | 3 walls, 15% gyroid | 0.2 | 23.6 | 1.84 | READY |
| torso_shell_back | v331_torso_shell_back.stl | 1 | PLA wood-brown | split face down; no supports | 3 walls, 15% gyroid | 0.2 | 23.9 | 1.85 | READY |
| torso_frame | v331_torso_frame.stl | 1 | PLA+/PETG any colour (hidden) | back rail face down (as exported); tree supports under the hip deck, neck cradle and the two strut columns/gussets | 4 walls, 30% gyroid (load path) | 0.2 | 88.6 | 6.48 | READY |
| hip_cradle | v39_hip_cradle.stl | 1 | PLA/PETG any (hidden) | flipped, seats up; supports under the T-arms | 4 walls, 30% | 0.2 | 10.9 | 0.93 | READY |
| hip_bracket_L/R | v39_hip_bracket_L.stl | 2 | PETG or PLA+ black | as exported (sleeve axis vertical); supports under the webs | 5 walls, 40% (load path) | 0.2 | 28.0 | 2.15 | READY |
| thigh_sheet_a | v39_thigh_sheet_a.stl | 2 | PLA **BLACK** (v3.32 recolour; was wood-brown) | flat | 4 walls, 40% | 0.2 | 4.7 | 0.48 | READY |
| thigh_sheet_b | v331_thigh_sheet_b.stl | 2 | PLA **BLACK** (v3.32 recolour; was wood-brown) | flat | 4 walls, 40% | 0.2 | 4.1 | 0.45 | READY |
| thigh_spacer | v39_thigh_spacer.stl | 2 | PLA black | flat | 4 walls, 40% | 0.2 | 5.0 | 0.51 | READY |
| boot_cuff | v39_boot_cuff.stl | 2 | PLA black | upright ring, no supports | 3 walls, 15% | 0.2 | 6.1 | 0.59 | READY |
| leaf_M (chest) | v39_leaf_M.stl | 1 | PLA green | veined face down, peg up | 100% | 0.12 | 0.3 | 0.2 | READY |
| leaf_S (vine) | v39_leaf_S.stl | 2 | PLA green | veined face down, peg up | 100% | 0.12 | 0.2 | 0.18 | READY |

Not in this pack: head_yaw_to_roll + chin collars and head/wig/snout/bezels (head owner; v3.30 head is final).

Set B: about 400 g / 34 h (rough, rev C / v3.32 estimates). Shin sheets and the other stock Open Duck Mini v2 parts print from the ODM repo.
Not in this pack: head_yaw_to_roll + chin collars and head/wig/snout/bezels (head owner; the hair worker is on the wig).

## Colour summary
- BLACK: gripper_housing, finger_moving, upper_arm + forearm brackets (v3.33), boots, boot_cuff, thigh_spacer, hip_bracket, thigh_sheet_a/b
- WOOD-BROWN: shoulder_sleeve + elbow_sleeve blocks (v3.33, were black), torso shells, shin covers
- GREEN: kilt petals, kilt_band (v3.33), arm leaves + vines (v3.33), chest vine, leaf_M
- ANY (hidden): torso_frame, hip_cradle

Removed vs v3.32: v331_leaf_cluster_shoulder (replaced by leaf_shoulder_L/R), 2 of the 3 leaf_M (elbow leaves -> leaf_elbow_L/R), v39_shoulder/elbow_sleeve (-> v334 jacketed blocks).

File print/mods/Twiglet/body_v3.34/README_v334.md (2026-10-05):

# Twiglet body v3.34: bigger hollow FEETECH gripper boxes + wider, flared kilt

All modelling was done in Blender (`body-v3.34-body/blender/body_v334.blend`, built from `body_v333.blend` / v333h; scripts `v334_arms.py`, `v334_kilt.py`).
Head and neck are v3.30 and unchanged. The renders and the wig-vs-arm sweep use `hair-v3.34/FINAL_WIG_model_frame.stl`.

## What changed
- **Gripper box:** 29 x 47 x 43 mm -> 36 x 47 x 57 mm. The photo box is ~42 x 62 with a ~47 mm face.
  - The box is longer along the forearm (about 52 mm of prong now shows below it, as in the photo) and deeper.
  - Still a HOLLOW shell: 1.6 mm walls, open bottom, same servo seat and finger. The housing grows 37.0 -> 41.7 cm3, about +5.8 g per side.
- **Kilt:** all 10 petals are wider and flare further out. Pointed leaf tips, layering and the band fit are kept.
  - Hem radius: front 98 -> 118, back 102 -> 122.
  - Hem height: the front petals stay at the v3.33 height; sides/back are 6 mm longer.
  - In the original view the whole kilt silhouette goes 151 x 120 -> 203 x 132 mm (photo 191 x 145), and kilt IoU .525 -> .608.
- Only 12 files changed: `v334_gripper_housing_L/R` and `v334_kilt_petal_00..09`. The other arm parts are the unchanged v3.33 files.

## Key metrics (metrics_v334.json)
- **Arm IoU at the best-fit pose:** front .565/.552 -> .597/.582; original .459/.536 -> .471/.568. At the rest pose: front .412/.406 -> .452/.442.
- **Mass:** 2.725 -> 2.753 kg (forearm +5.8 g per side, kilt +15.7 g).
- **Sim (policy v334r1, a light retune of v333r1):**
  - e-margin 34.0 mm; head pitch about 2.36x
  - max-speed gait 20/20 at 0.208 m/s; efficient gait 20/20 at 0.156 m/s; held-out seeds 19/20
  - Without the retune, v333r1 scored 19/20.
- **Checks:**
  - All parts are watertight single bodies. Elbow and gripper sweeps 0. Arm sweep 0/162. The shoulder hits only at -10°, outside the soft limits (same as v3.33).
  - Head range 154/315 and exact head x upper-arm 121, both identical to v3.33.
  - Wig-arm with the v3.34 wig: 0 hits inside the soft limits for all 3 registration fits.
  - Kilt swing in the walking gaits 0/1500 for legs and arms.

## Open items
- **Front width:** in the front views the kilt is capped by the arm corridor. The arms hang at |y| >= 67.7 and swing through the whole front half, so the front hem width is 124 -> 135 mm, not 191.
  - Getting closer needs the shoulders moved out about 10-15 mm (a spacer), or flexible TPU side petals that the arms push aside.
- **Synthetic leg grid:** gait120 extreme-knee poses give single-leg 12 (v3.33 8) and both-legs 1 (v3.33 3).
  - It is the swing foot touching under the flared front hem at knee 55-96°. The real walking gaits are contact-free.
- **Wig placement:** registered by ICP (about ±2 mm), because the exact hair transform was lost in the 04:15 box restore.
- **Order of checks:** parts_check, arm_check and hb were run on v334a, whose front petals were 6 mm longer, so they are conservative for the final v334b.

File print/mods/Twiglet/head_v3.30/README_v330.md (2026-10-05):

# Twiglet head v3.30

## What changed vs v3.29 (nothing has been printed yet)
- WIG: the locks are now modelled in Blender (`blender/`, see `README_blender.md`). The v3.29 lock layout, smooth central fringe triangle,
  soft sideburns and temple flicks are kept. The locks are smooth, sleek and blended, with no serrated or clumpy edges.
  The seat, 4 pins, key and hat band are unchanged (procedural).
- SNOUT (Blender 4.5: `blender/face_v330_bpy.py`, with a 3 mm root fillet and wood-grain grooves; `snout_v330.py` was the Python draft): re-aimed from yaw -12 / pitch -6 to yaw -4 / pitch +22 deg, still 72 mm long. This raises the mouth to match the photos.
  It keeps the keyed spigot into the head_lower socket, and the root is trimmed inside the head-split lift cylinder.
- EYES (Blender 4.5: `blender/face_v330_bpy.py`; `eyes_v330.py` was the first Python draft and is not used): both eye assemblies are 4 mm lower (bezel + display carrier + screen move together; the 2 M3 carrier posts in head_lower are
  4 mm shorter with re-drilled heat-set insert holes; the lift sweeps are extended).
  The rings are round revolved bezels and smaller: dark disc 70.8 mm (was 74.4), window 59.6 mm, ring 5.6 mm wide.
  The flat wooden rim is wider (flat to rho 42, blend to 49 mm; 6.6 mm of flat wood around the ring, was 2.8).
  The old openings are filled back into the ball wall and re-cut.
- Head-half joint (4 M3 screws into heat-set inserts) and head_upper pin holes / key groove: unchanged.

## STLs (twiglet-head-v3.30-stl.zip = the WHOLE head set, print-ready)
Changed in v3.30: wig, snout, head_upper, head_lower, eye_bezel_L, eye_bezel_R, display_carrier_L, display_carrier_R (re-exported 4 mm lower).
Unchanged, included for completeness: chin_collar_L, chin_collar_R. The kilt pack is separate and unchanged.
Print: the shells, snout and collars in brown PETG; the wig in yellow PLA (lightning infill, tree supports); the bezels and carriers in black PLA (see print_note_head_v330.md).

## Scripts
eyes_v330.py, snout_v330.py, head_v330.py, hair_v330.py, face_v330.py (landmarks), render_v330.py, edge_render_v330.py, export_head_v330.py, blender/*.

## v3.30 head-range relief on the v3.31 rev C body (chin collars)
- CHIN COLLARS L/R changed (Blender 4.5, `blender/trim_collars_v330.py` on `head_v330.blend`; cutters from `blender/trim_v330/mk_collar_cutters.py`):
  side-hem relief: the band below 4.1 mm from the collar top is removed 64-122 deg either side of the chin (cosine ramps), so the collars clear
  the upper arms when the head rolls. Front 0-64 deg, both screw tabs (50 / 130 deg) and their holes untouched; wall 2.2-2.5 mm unchanged; one piece each.
  Plus a 1.8 mm clearance notch under the snout root (the v3.30 re-aimed snout overlapped the collar top-front edge by 0.6 mm3; now 0).
  10.33 -> 8.12 cm3 each. head_lower, snout, shells, wig, bezels, carriers unchanged.
- Whole printed head vs rev C torso shells / frame / leaves / kilt / arms at rest (315 poses, exact meshes): 235 -> 221 poses with contact; neutral overlap 0.
  Clean range from level: roll +-9 -> +-15 deg; forward pitch -45 (full); yaw +-160; back pitch +10 (unchanged).
- Not trimmed: head_lower back edge. The back-pitch contact is the roll-bearing holder tube that hangs below the shell at the back, not the shell edge.
  What-if (not applied): removing the holder alone gives +12; holder + rear collar segment gives +37 at yaw 0. The 4 collar screw tabs block most roll/yaw combinations.
- Checks: `blender/trim_v330/` (collar_trim / wall_collars / thin_check / post_checks json), `revC/head_body_check_trimF.json`, `simC/sweepF.txt`, `renders/collar_trim_v330_before_after.png`.

## v3.30 head-range redesign (roll-bearing holder + collar fixing + neck part) - supersedes the "Not trimmed" note above
- CHANGED: head_lower, chin_collar_L/R and head_yaw_to_roll (NECK MECHANICS part - print it instead of v39_head_yaw_to_roll from the body pack).
- head_lower: old inclined bearing strut / housing / lower hanger removed; new deck-hung housing for the same 20x32x7 bearing 12.1 mm further
  forward on the same roll axis (1.8 mm wall, bottom window, rear lip); 4 external collar tabs removed -> 4 internal bosses with vertical
  M3x5x4 heat-set inserts; back-bottom rim relieved (hidden from the front); rear ballast ledge for 25 g steel (keeps head-pitch hold >= 2x).
- chin collars: front band only (0-64 deg either side of the chin, look unchanged), 2 inward ledges each, M3x8 from below into the inserts.
- head_yaw_to_roll: tower + hub moved 12.1 mm forward (hub still slides 7 mm into the bearing), rear ring sector replaced by cross-bar + side arms.
- Range on rev C (exact, arms at rest): yaw-0 back pitch +9 -> +26 (bearing-limited; printed head alone +30), roll +-15 -> +-18; grid counts in
  revC/head_body_check_rd.json; mechanism limits fwd -36 and back +18 at yaw != 0 (neck yaw ring) unchanged.
- Not done (options): +35 back pitch needs a smaller roll bearing (e.g. 688 / 6800, ~+32-34) or a lower torso back; +-30 roll needs cutting the
  visible ball sides; yaw +-40..160 roll is limited by the collar front band at 48-64 deg (trim = front-corner look change).
- Scripts / checks: blender/redesign_v330.py, blender/redesign_v330/ (mk_redesign_parts.py, load_redesign.py, post_checks_rd.py, STATUS.md),
  simC/sweepR2.txt, renders/head_range_redesign_v330_before_after.png.

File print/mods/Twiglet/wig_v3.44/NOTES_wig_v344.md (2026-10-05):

# Wig v3.44 (hair v3.44, final variant c14)

One-piece printed wig that sits on `head_upper` (4 pins + keyed tongue, same cap/pin fit as v3.30-v3.43).

| | v3.40 (y2) | v3.43 (b6) | **v3.44 (c14)** |
|---|---|---|---|
| mass at 4.5 % lightning | 176.4 g | 182.4 g | **186.2 g** (budget 186.5 g) |
| head-pitch hold on the hair base body (`quick_static`, 0.4897 N·m / ctrl) | 2.13× | 2.112× | **2.151×** (ctrl 0.2277); 2.297× with the skin-COM estimate |
| head-pitch hold on the v3.34 body (this repo, 0.49 N·m / ctrl) | 2.09× | – | **2.11×** (ctrl 0.2323) |
| eye coverage / overlaps | 0 / 0 | 0 / 0 | **0 / 0** |
| wig vs arms inside the soft limits (yaw 0/−45/+45) | 0/0/0 | 0/0/0 | **0/0/0** (raw 3/32/38) |
| 315-pose head range: any contact / wig contact / wig-only | 154 / 34 / 0 | 154 / – / 0 | **154 / 32 / 0** |
| min wall (60k copy) | – | 2.41 mm | **2.39 mm**, none < 2 mm |
| mesh | watertight | watertight | **watertight, 1 body, 59,984 faces, 624.9 cm³** |
| print size (oriented) | 248 × 223 × 242 mm | – | **243.1 × 246.4 × 239.9 mm** (fits the P1S), support ~473 cm³, overhang 212 cm² |

What changed from v3.43 b6 → v3.44 c14:
- fuller side curtains (S1 lower half ×1.8, split into 2 felt-like blades) and longer sideburn lower halves, front fringe blades thinned 6.0 → 5.2 mm;
- longer central lock tip; back locks B1/B2 lifted 1.5 mm (they are the head's pitch counterweight, so the hidden back hair was kept);
- hidden-under-hat squash in front of the pitch axis only (fades out by θ 24–28°);
- crown closed again (c13 had a top opening); the hidden crown top under the hat (θ < 14°) thinned 7.5 → 3.0 mm and the side-curtain blades 6.5 → 5.6 mm to stay inside the mass budget.

Files: `FINAL_WIG.stl` (print this; print-oriented, crown axis 38° from straight down, centred, z0 = bed), `FINAL_WIG_model_frame.stl` (same mesh in the head model frame, used by the sims/checks), `final_export.json` (export report). Blender source: `../source/blender/hair_v344.blend` (object `FINAL_WIG_v344_c14`). Edit set: `../source/scripts/wig_v3.44/variants/c14.*`.
Print settings: [docs/print_guide.md](../../../../docs/print_guide.md).

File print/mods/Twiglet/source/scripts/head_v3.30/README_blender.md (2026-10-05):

# v3.30 wig locks in Blender: handover

Blender 4.2.23 LTS (headless): `$BLENDER (4.2 LTS)`.

## Files
- `locks_v330.json`: the 21 lock spines exported from the v3.29 procedural wig (`export_locks_v330.py`). Each lock has n = 48 samples, and each sample stores
  B (spine point on the seat, mm, head frame), N (normal), L (unit direction), W (full width), H (crest height), plus params/style/name.
- `build_wig_v330.py`: JSON (or `--from-blend`) -> Bezier spines (collection "LockSpines": point co = spine, point radius = half width,
  point weight_softbody = crest height; object props lip / p_top / off) -> loft (superellipse top p_top on a 2 mm side wall, buried 4 mm,
  NA 32 around, NT 96 along) -> SUBSURF 2 -> join -> voxel remesh 0.7 mm -> Taubin smoothing (0.5 / -0.53, 20 iterations) -> STL.
  The defaults are the shipped v3.30 tuning: `--hs 0.8 --ws 1.15 --ptop 1.4 --voxel 0.7`, ARM_H 0.55 forearm easing, plus the
  per-lock TWEAK table (fringe / front-side / temple crests x1.12, sideburns L13/L14 width x0.8). `--no-tweak` disables the tweaks and `--ovr file.py` runs extra code on SP.
- `wig_v330.blend`: the spine curves, lofted locks and final mesh. `wig_locks_v330.stl`: the build's output, read by `hair_v330.wig_blend`.
- `lock_table_v330.md`: per-lock root/mid/tip (th, phi), length, widths, crest, curl/wave/twist.

## Editing a lock
1. Open `wig_v330.blend`. In "LockSpines", move the curve points of the lock (e.g. `L03_F4`). To make it wider, scale the point radius
   (Alt-S). The crest height is the point's softbody weight. Save.
   You can also edit `locks_v330.json` (B / W / H of the samples).
2. Rebuild the locks: `blender -b -P blender/build_wig_v330.py -- --from-blend blender/wig_v330.blend` (or omit `--from-blend` to use the JSON).
3. Rerun the head chain: `python head_v330.py && python design_v3.py`, then the checks (headrange_v320, armsweep_v330, measure_v330,
   wallsec), then `export_head_v330.py`.

## Reused procedural parts (hair_v330.py)
- `seat_r(env, u)`: seat radius = shell envelope + 0.3 mm glue gap. `height(locks=[])`: crown dome + floor + hat seat + PIN_BOSS (+ HAT / hat_cap recessed felt-hat band).
- `attach_parts`: 4 vertical pins (PINS (th 20, phi 45/135/225/315), PIN_R 1.6, PIN_DEPTH 5.0) + keyed tongue (KEY: TH 31, arcs 70/40/40/40, W 2.4, H 1.1).
- `trim_k(u)`: arm / trunk relief factor. `wig_blend(env, cuts, sub)`: crown + the Blender locks squashed radially by (1 - k), sunk SINK k^2,
  with relieved tips that either keep >= MINP 1.4 mm above the seat or dive under it. Then hat-cap clip, minus the seat, + key tongue,
  minus eye / snout / collar cuts and pin holes.
- `head_v330.py`: cuts = eye-bezel hulls x1.012, snout hull x1.02, chin-collar hulls. Envelope cache `.cache/env_v314.npz`.

# v3.30 face (eyes / bezels / shell openings / snout) in Blender 4.5 LTS

Blender 4.5.9 LTS (headless): `$BLENDER (4.5 LTS)`. All booleans use the MANIFOLD solver (Blender 4.2's EXACT solver
broke the 300-600k-face shells).
1. `python blender/prep_face_inputs_v330.py`: data hand-off only. It writes the unchanged v3.29 parts as STL plus `params.json`
   (ball centre/radius, split height, carrier posts, socket frame, pod pieces) to `blender/in_v329/`. In float32, Blender would snap vertices
   closer than ~3e-5 mm onto each other, so those pairs are pushed 1.5e-4 mm apart first.
2. `blender -b -P blender/face_v330_bpy.py -- [--dz 4.0]`: all modelling. Output goes to `blender/out_v330/*.stl` + `face_info.json`, and the scene is saved
   to `blender/head_v330.blend` (collections v329_input / tools / v330; the tools collection holds every cutter, so the edits can be inspected and re-run).
   - Eyes: 4 mm lower; round revolved bezels (dark disc 70.8 mm, window 59.6 mm, ring 5.6 mm); flat wood rim to rho 42, blend to 49
     (constants R_OUT / R_WIN / R_SPIG / R_BORE / RF / RB / DZ at the top of the script). The old openings are refilled with a ball-wall cap, then
     the facet, blend, bore, ring pocket, 4 grain rings and backing ring are re-cut about the lowered eye frame. The carriers move down DZ, and their
     2 M3 posts are shortened DZ with the heat-set insert holes re-drilled. The pod and bezel lift sweeps are extended.
   - Snout: revolved cone (OD 65 -> 72 mm, L 72, 3 mm rounded mouth rim) on yaw -4 / pitch +22, a 3 mm concave root fillet onto the ball,
     39 wood-grain grooves (0.9 x 0.45 mm), and the keyed spigot + flush plug on the unchanged head_lower socket frame. Then minus the bezel hulls,
     the pod lift sweeps and the head-split lift cylinder.
3. `blender -b blender/head_v330.blend -P blender/stl_safe_v330.py -- eye_bezel_L eye_bezel_R display_carrier_L display_carrier_R snout head_lower head_upper`: float32-safe export (weld, delete zero-thickness coincident face pairs, dissolve slivers, fill micro-holes), then re-imports every STL and gates it (all edges 2 faces, 1 body, volume vs in-memory; results in `out_v330/stl_safe.json`). Replaces the older destructive `stl_clean_v330.py` loop.
   Result: every STL re-imports with 0 open / 0 non-manifold edges and 1 body; volume change vs the exact solver mesh < 0.01 %.
4. `python blender/load_face_v330.py`: loads the Blender STLs into the head-chain caches. Then run `head_v330.py` and the checks.

## v3.30 chin-collar relief (head range)
1. `python blender/trim_v330/mk_collar_cutters.py` (run inside trim_v330/): hem cutters (model frame), `collar_cutter_L/R.stl`; `snout_clear_cutter.stl` = snout convex hull x1.02.
2. `blender -b blender/head_v330.blend -P blender/trim_collars_v330.py`: imports the untrimmed collars (`trim_v330/chin_collar_*_v329.stl`) into collection
   `v330_collar_trim`, MANIFOLD Boolean minus both cutters, float32-safe export + gate -> `out_v330/chin_collar_L/R.stl`, `out_v330/collar_trim.json`; saves the blend
   (untrimmed scene: `trim_v330/head_v330_pretrim.blend`).
3. `python blender/trim_v330/load_trim.py`: puts them into `.cache/head_v330.pkl` and both `v3model.pkl` (pre-trim copies `*_pretrim.pkl`).
4. Zip: `blender/decimate_v330.py` ratio 0.67 -> `out_v330/collars_dec/` (max deviation 0.012 mm), then `export_head_v330.py`.

## v3.30 head-range redesign (holder, collar tabs, neck)
1. `cd blender/redesign_v330 && python mk_redesign_parts.py` -> cutter / adder STLs (head parts model frame, neck print frame) + redesign_parts.json.
2. `blender -b blender/head_v330.blend -P blender/redesign_v330.py`: inputs `redesign_v330/in/*` (pre-redesign v3.30a), MANIFOLD Booleans,
   float32-safe export + gate -> `out_v330/{head_lower,chin_collar_L,chin_collar_R,head_yaw_to_roll}.stl`, `out_v330/redesign.json`; saves the blend
   (pre-redesign scene `redesign_v330/head_v330_preredesign.blend`).
3. `python blender/redesign_v330/load_redesign.py`: caches (head_v330.pkl, both v3model.pkl; bearing +12.1 mm, neck part, 25 g ballast_back).
4. `python blender/redesign_v330/post_checks_rd.py` -> post_checks_rd.json (overlaps, hardware, neck vs head in roll / yaw, lift, eye cover, thin).
5. Zip: `export_head_v330.py` (collars no longer decimated; head_yaw_to_roll emitted from out_v330).

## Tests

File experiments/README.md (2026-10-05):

# Experiments

These are undocumented experiments, some of them very old. I wouldn't recommend trying to run them :)

(That is upstream's note. Upstream's experiments (LeRobot, RL, placo, mujoco, v2, ...) are not copied; see https://github.com/apirrone/Open_Duck_Mini/tree/v2/experiments.)

Twiglet keeps every simulation we ran for the Twiglet robot here, in a form that re-runs from a fresh clone. Nothing has been checked on hardware yet.

| folder | what |
|---|---|
| [`twiglet_sim/`](twiglet_sim/README.md) | MuJoCo sims: standing, push, head + arm motion, head-pitch load, both walking gaits, gait search/refine, held-out seeds, arm heating, videos. 52 MJCF models (body v3.20 to v3.34, head/wig infill sweeps, the hair series, studies) and all 22 gait parameter files |
| [`twiglet_geom/`](twiglet_geom/README.md) | Mesh/collision checks on the assembled v3.34 + wig v3.44 scene (trimesh + FCL): 315-pose head range, wig vs arms, eye coverage, arm sweeps, kilt swing, print-file checks. Also renders the assembly-guide images |
| [`twiglet_eyes/`](twiglet_eyes/README.md) | Firmware for the two ESP32-S3 round-display eyes, plus the Pi helper |
| [`history/`](history/README.md) | Read-only archive of the results of every earlier version (body v2 to v3.34, hair v3.33 to v3.41, head v2, head v3 digital eyes): 1239 json/txt/md/csv/log files, 18 short mp4s and the sim plots. [`history/sim_history.md`](history/sim_history.md) is the per-version table |
| `tools/` | `history_table.py`, which rebuilds `history/sim_history.{csv,md}` |

Setup (any Python ≥ 3.10):
```bash
pip install mujoco numpy            # twiglet_sim
pip install trimesh python-fcl scipy manifold3d pyvista   # twiglet_geom (pyvista only for render_assembly.py)
```
All scripts use paths relative to the repo. Outputs go to `twiglet_sim/out/` and `twiglet_geom/out/` (both gitignored). The reference results are in each folder's `results/`, and the scripts never overwrite them.

## Index

Current robot: body **v3.34** + head **v3.30** + wig **v3.44** (c14) = model `twiglet_sim/models/twiglet_v3_v334_wig344.xml` (2.753 kg, head 0.814 kg) and scene `twiglet_geom/scene/scene_v334_wig344.npz`. Gaits: main `walk_v3_best.npy` (= `params/walk_v3_best_v334r1.npy`), efficient `walk_v3_eff_best.npy` (= `params/walk_v3_eff_best_v333r1.npy`).

"Latest" is the newest run. ✅ = re-run from this repo copy on 4 Oct 2026 (wig v3.44 rows: 5 Oct 2026); the others are copied from the original run records.

| # | sim | what it checks | how to run (from the folder) | latest result | pass criteria |
|---|---|---|---|---|---|
| 1 | standing margin (`run_tests.py` a) | static COM margin inside the support polygon, crouch 0.10, plus the open-loop COM window | `TWIGLET_XML=twiglet_v3_v334_wig344.xml python run_tests.py v3` | ✅ 50.5 mm (v3.34 body alone: 50.8) | no fall, margin > 30 mm (TODO: no formal limit in the records; v3.x ran 41–51) |
| 2 | push recovery (`run_tests.py` b) | largest impulse survived, with and without the balance controller | same run | ✅ with controller: fwd 1.59 / back 1.01 / left 1.81 / right 1.83 N·s | informative (no fixed limit) |
| 3 | weight shift / single support (`run_tests.py` c) | hip-roll sine shift; single-leg stance attempt | same run | ✅ in `results/v334_wig344/results_v3.json` | no fall at the 0.05–0.15 amplitudes |
| 4 | head + arm motion, neck load (`run_tests.py` e) | full head pitch/yaw/roll + arm waving while standing: min support margin and the peak servo torques (head-pitch headroom) | same run | ✅ e-margin **34.1 mm**, head pitch peak **0.796 N·m** = 2.40× the STS3215 stall (1.91 N·m); static hold 0.232 N·m = 2.11× the 0.49 N·m rating; v3.34 alone 34.0 / 0.808 (2.36×) | no fall, e-margin ≥ 30 mm, head-pitch hold ≥ 2× |
| 5 | main gait (`walk_eval.py`) | 10 s nominal walk + 20 randomized trials (mass ±10 %, friction, armature, latency…) | `TWIGLET_XML=twiglet_v3_v334_wig344.xml python walk_eval.py v3` | ✅ **19/20** at 0.206 m/s (wig v3.40: 20/20 at 0.210; v3.34: 20/20 at 0.208) | ≥ 19/20 |
| 6 | efficient gait (`walk_eval.py --eff`) | same, energy-aware gait | `... python walk_eval.py v3 --eff` | ✅ **20/20** at 0.156 m/s | ≥ 19/20 |
| 7 | held-out seeds (`walk_heldout.py`) | the main gait on 20 seeds never used in the search (6000–6019) | `TWIGLET_XML=twiglet_v3_v334_wig344.xml python walk_heldout.py v3 walk_v3_best.npy <tag>` | ✅ **18/20** at 0.206 m/s (wig v3.40: 19/20 at 0.202; v3.34 record: v334r1 = s35 19/20 at 0.207; s34 17/20, s36 18/20, v333r1 19/20 at 0.187) | ≥ 18/20 |
| 8 | all of 1–6 in one go (`run_all.sh`) | runs tests + both gaits for one model, logs to `out/<tag>/`, one line to `out/sim_summary.txt` | `./run_all.sh twiglet_v3_v334_wig344.xml mytag` | ✅ v334_repo, v334_wig340 and v334_wig344 (`results/sim_summary_repo_runs.txt`) | as 1–6 |
| 9 | gait refine (`walk_refine.py`) | local refine of a gait for a new body: 24 perturbations × 10 seeds; how v334r1 (= s35) was found | `TWIGLET_XML=... python walk_refine.py v3 [--eff]` | v3.34: s35 picked (`results/record_v334_r2/walk_refine_v334s3*.json`) | better success × speed than the start params |
| 10 | gait search (`walk_search.py`) | random search + CEM from scratch (12 params), then the robustness check | `python walk_search.py v3 [N] [--eff]` (hours; writes `out/*_search*`) | origin of the gait lineage in `params/` (see `params/MANIFEST.json`); not re-run | as 5/6 |
| 11 | arm heating (`arm_heat.py`) | 30 s continuous arm waving while standing: STS3032 RMS torque vs rated (0.147 N·m), copper loss | `TWIGLET_XML=twiglet_v3_v334_wig344.xml TWIGLET_RESULTS=results/v334_wig344/results_v3.json python arm_heat.py v3` | ✅ shoulder RMS/rated: **0.87× at 0.5 Hz**, 1.04× at 0.8 Hz, 1.70× at 1.5 Hz (v3 record: 0.99× at 0.8 Hz, 1.63× at 1.5 Hz → "cap continuous waving at ~0.6 Hz"; on v3.34 the cap should be ~0.5 Hz) | RMS ≤ 1.0× rated for continuous waving |
| 12 | head+arm diagnosis (`diag_e.py`) | test (e) alone with searched or fixed balance gains | `python diag_e.py v3 [g1,g2,g3,g4,g5]` | rev B1/C records in `history/body-v3.30/simC/` | as 4 |
| 13 | walk video (`walk_video.py`) | renders the gait to GIF/MP4 + torque traces (needs an OpenGL backend) | `MUJOCO_GL=egl python walk_video.py v3 [--eff]` | old videos (v2–v3.2) in `history/`; none for v3.3x | – |
| 14 | body version sweep | the same sims on every body v3.20–v3.34 model | `./run_all.sh twiglet_v3_body_v325.xml v325` etc. | per-version table: [`history/sim_history.md`](history/sim_history.md) | as 1–6 |
| 15 | head/wig infill sweep (simC) | head v3.30 variants (head330 / rd / trim / trimF) × wig infill 0–6 %: head mass vs e-margin and head-pitch load | `./run_all.sh twiglet_v3_head330rd_0.045.xml rd045` etc. | rd: infill 0 → 6 %: head 0.781 → 0.826 kg, e-margin 33.5 → 32.1 mm, head pitch 0.777 → 0.825 N·m (`history/body-v3.30/simC/sweepR2.txt`); 4.5 % chosen | all pass 1–6; head-pitch hold ≥ 2× |
| 16 | hair series | wig candidates s16 … y2 (v3.34–v3.40), c14 (v3.44) on the hair base body | `./run_all.sh hair_c14_v344.xml c14` etc. | c14 (= v3.44): pitch 2.151× hold on the hair base body (186.2 g wig); y2 (= v3.40): margin 33.4, standing 46.5, pitch 2.13× (`history/hair-v3.40/STATUS.md`) | pitch ≥ 2.0×, no falls |
| 17 | studies | neck 40 mm shorter (+ legs), no arms / arms only | `./run_all.sh twiglet_v3_opt_neck40_leg40.xml n40l40` etc. | v3.32 records: opt_neck40 main 13/20; neck40_leg40 20/20; s_noarm 19/20; s_armonly 18/20 | informative |
| 18 | mass / moment (`tools/mass_v334.py`, `tools/make_v334_wig.py`) | link masses and inertias from the meshes + densities; wig head inertial | `python tools/make_v334_wig.py` (runs; `mass_v334.py` is provenance only) | 2.753 kg total, head 0.814 kg (wig 186.2 g at 4.5 % infill) | head pitch hold ≥ 2× |
| 19 | 315-pose head range (`twiglet_geom/head_range.py` part 2) | head pitch × yaw × roll grid (7×9×5) vs trunk and arms | `python head_range.py` (3.5 min) | ✅ **154/315** poses with a contact (= v3.33h/v3.34 record), wig contact 32, wig-only **0** (wig v3.44) | ≤ ~154/315 and wig-only 0 |
| 20 | wig vs arms (`head_range.py` part 1) | wig vs both arms over the arm grid at head yaw 0/−45/+45 | same run | ✅ raw 3/27/35, **0/0/0 inside the arm soft limits** | 0 inside the soft limits |
| 21 | eye coverage (`twiglet_geom/eye_cover.py`) | wig triangles in front of the eye openings | `python eye_cover.py` | ✅ L/R **0/0** | 0/0 |
| 22 | arm sweeps (`twiglet_geom/arm_sweep.py`) | arms vs shells, kilt, leaves, head (162 poses) + per-joint sweeps | `python arm_sweep.py` | ✅ 0/0/0; elbow and gripper 0; shoulder 1 hit only at −10° (outside the −5° soft limit) | 0 inside the soft limits |
| 23 | kilt swing (`twiglet_geom/kilt_swing.py`) | kilt petals vs legs and arms over the shipped gaits + random poses | `python kilt_swing.py [--fast]` | ✅ sim gaits **0/1500** (leg 0, arm 0), stance **0/14**; single-leg 12/120, both legs 1/120, arms+legs 1/80, all front petals 00–02 vs a foot (= the v3.34b record) | sim gaits 0; random-pose hits only at extreme angles (free-swinging petals) |
| 24 | print-file check (`twiglet_geom/print_check.py`) | every STL in `print/mods/Twiglet`: watertight, 1 body, P1S fit, wall survey | `python print_check.py [subfolder]` | ✅ **61/61 pass** (50 body + 10 head + wig) | watertight, 1 body, fits 256³ |
| 25 | assembly renders (`twiglet_geom/render_assembly.py`) | the 26 step images of [docs/assembly_guide.md](../docs/assembly_guide.md) | `python render_assembly.py [step]` (15 s) | ✅ 26 PNGs in `docs/images/assembly/` | – |

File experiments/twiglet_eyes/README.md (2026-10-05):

# twiglet_eyes: digital-eye firmware (Twiglet)

There are two Waveshare **ESP32-S3-Touch-LCD-2.1** boards (flat, SKU 28169), one per eye. Both run the same sketch, and the Pi Zero 2W drives them over one UART.

- `TwigletEyes/`: the Arduino sketch. The ST7701 init sequence, pins and timings are ported from Waveshare's official demo.
- `pi_eyes.py`: the Pi helper (pyserial).
- `eyes_art.py`: generates `eye_bitmaps.h`.
- `compile_log.txt`: the sketch compiles with arduino-cli and esp32 core 3.3.12. It has not been tested on hardware (TODO).

The text below is copied from the head-v3 digital-eyes notes. TODO: confirm the eye mounting on head v3.30.

## 5. Wiring (Pi Zero 2W ↔ eyes)

```
Pi pin 8  GPIO14 TXD ──┬──> L board 12-pin #10 RXD (GPIO44)
                       └──> R board 12-pin #10 RXD (GPIO44)
Pi pin 10 GPIO15 RXD <──── L board 12-pin #9  TXD (GPIO43)     (R board TXD not connected)
Pi pin 6  GND ─────────── both boards pin #1 (or #5) GND
5 V rail ──────────────── both boards pin #2 VBus 5 V
```

**12-pin header**

| Pin | Signal |
|---|---|
| 1 | GND |
| 2 | VBus 5 V |
| 3 | D− / GPIO19 |
| 4 | D+ / GPIO20 |
| 5 | GND |
| 6 | 3V3 |
| 7 | SCL GPIO7 |
| 8 | SDA GPIO15 |
| 9 | TXD GPIO43 |
| 10 | RXD GPIO44 |
| 11 | NC |
| 12 | GPIO0 |

- **Pi setup:**
  - `raspi-config` → Serial: login shell **no**, hardware **yes**.
  - Add `dtoverlay=disable-bt` to `/boot/firmware/config.txt` so `/dev/serial0` is the PL011.
  - The ODM's servo bus runs over USB, so the GPIO UART is free.
  - The helper is `pi_eyes.py` (pyserial).
- **UART sharing:** GPIO43/44 are also wired to the board's "UART" USB-C port (CH343 through a mux). Unplug that USB-C when the Pi is driving the eyes.
- **Cable route:** the 12-pin header points down/inward through the carrier notch and the cable exit in `head_lower`. Run the cable along the deck to the Pi and zip-tie it through the carrier slots. Put the inline connector near the deck.

## 6. Firmware (`TwigletEyes/`)

`TwigletEyes.ino`, `st7701_panel.cpp/.h`, `eye_bitmaps.h` (generated by `scripts/eyes_art.py`) and `eye_geometry.h`. Both boards run the same sketch.

**Arduino IDE settings**
- Board: ESP32S3 Dev Module (esp32 core ≥ 3.0; tested to **compile** on 3.3.12)
- PSRAM: **OPI PSRAM**
- Flash: 16 MB; partition "16M Flash (3MB APP/9.9MB FATFS)"
- USB CDC On Boot: **Disabled**, so `Serial` is UART0 on the header and the UART USB-C
- Flash through the "UART" USB-C.

**Protocol:** 115200 8N1, one command per line, case-insensitive. Add `L:` or `R:` in front to address one eye.

| Command | Effect |
|---|---|
| `EYE ring` | default: thick orange ring, dark pupil, auto-blink |
| `EYE heart` | beating pixel heart |
| `EYE happy` | ^ ^ arch |
| `EYE angry` | ring with a lid slanted down toward the nose; mirrored per eye |
| `EYE wide` | surprised |
| `EYE blink` / `BLINK` | one blink: 7 frames × 55 ms |
| `EYE off` | backlight off |
| `EYE test` | calibration pattern |
| `LOOK x y` | x, y from −1 to 1. +x is toward the robot's own left, +y is up. Moves ±4 / ±3.5 dots. |
| `AUTOBLINK 0/1`, `BRIGHT 0..100`, `COLOR ff7a00` | settings |
| `SIDE L/R`, `ROT 0..3`, `MIRROR 0/1`, `CENTER x y`, `SAVE`, `INFO`, `PING`, `ECHO 0/1` | setup and diagnostics |

- Only the L board replies (`OK …`), because only its TX is wired back.
- Settings are saved to NVS with `SAVE`.
- Wi-Fi and BT are off.
- The ST7701 init sequence, pins and timings are ported from Waveshare's official demo.

**First-time setup per board**
1. Flash the sketch.
2. `SIDE L` (or `R`), then `SAVE`.
3. Install the board, send `EYE test`, and look through the opening:
   - The arrow must point up and the green dot must be on the viewer's right.
   - If it's wrong, adjust `ROT` / `MIRROR`.
   - Adjust `CENTER x y` until the grey circle sits concentric with the bezel.
4. `SAVE`.

The defaults in `eye_geometry.h` come from the CAD: L centre (218, 217), rot 2; R centre (263, 262), rot 3. **The panel's native scan orientation isn't documented, so treat these defaults as a starting point.**

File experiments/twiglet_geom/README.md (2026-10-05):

# twiglet_geom: mesh / collision checks on the assembled robot

These checks complement `../twiglet_sim/`. MuJoCo there only simulates foot-floor contact, so part-to-part clearance is checked here on the real print meshes, with trimesh + FCL.

**Scene:** `scene/scene_v334_wig344.npz` (10 MB) is the v3.34b rest-pose assembly in the assembly frame (mm; x forward, y left, z up). It has 133 meshes grouped by MuJoCo link, plus the 19 joints in its JSON metadata. The head fringe is replaced by the hair v3.44 (c14) wig (`print/mods/Twiglet/wig_v3.44/FINAL_WIG_model_frame.stl`, decimated to 40k faces) by `tools/swap_wig_scene.py`, which runs from the repo. `scene/head_meta.json` holds the head-ball centre. Use another scene with `TWIGLET_SCENE=<path>`. `tools/export_scene.py` is how the original (wig v3.40) npz was made (provenance only: it needs the original Blender build workspace).

Items whose names start with `sim_` are lumped masses from the sim (boards, battery, screws), not printed parts. Servos and horns are the stock ODM / STS3032 meshes.

```bash
pip install trimesh python-fcl scipy numpy mujoco manifold3d   # + pyvista for render_assembly.py
python head_range.py     # 3.5 min
python eye_cover.py
python arm_sweep.py
python kilt_swing.py     # ~20 min (uses ../twiglet_sim for the MuJoCo FK and the gaits); --fast = main gait only
python print_check.py    # every STL in print/mods/Twiglet (a few minutes; parts > 100k faces get their wall survey on a 60k-face copy)
python render_assembly.py   # the docs/images/assembly/ step images (15 s)
```

Outputs go to `out/` (gitignored; override with `TWIGLET_GEOM_OUT`). The reference results are in `results/`; copy a new run there by hand when it should become the reference.

| script | checks | result (wig v3.44, 5 Oct 2026, from this repo) | pass |
|---|---|---|---|
| `head_range.py` | (1) wig vs both arms at head yaw 0/−45/+45 over 156 arm poses each; (2) 315-pose head pitch × yaw × roll grid vs trunk and arms | (1) raw hits 3/32/38, **0/0/0 inside the arm soft limits**; (2) **154/315** poses with any contact (= the v3.33h/v3.34 record), wig contact 32, wig-only **0** | (1) 0 in soft limits; (2) ≤ ~154 and wig-only 0 |
| `eye_cover.py` | wig triangles inside each eye's 26.7 mm viewing cylinder | **0 / 0** | 0/0 |
| `arm_sweep.py` | arms vs shells, kilt, leaves and head (162 poses); elbow, gripper and shoulder joint sweeps | 0/0/0; elbow 0, gripper 0; shoulder 1 hit only at −10° (outside the −5° soft limit; same as the record) | 0 inside the soft limits |
| `kilt_swing.py` | kilt petals (+ band stand-in) vs leg and arm links: 1500 poses from both shipped gaits (nominal + 2 randomized seeds), 120 single-leg, 120 both-leg, 80 arms + legs, the stance series | ✅ wig v3.44 (`--fast`, main gait only): sim gaits **0/750**, stance **0/14**; single-leg 12/120, both legs 1/120, arms+legs 1/80 (= the v3.34b record). Full run with wig v3.40: 0/1500. The kilt check does not involve the wig | sim gaits 0 and stance 0; the random grids are informative (record v334b: 12 / 1 / 1) |
| `print_check.py` | watertight, 1 body, volume, P1S fit (256³), wall-thickness survey | **61/61 pass** (50 body, 10 head, wig; the v3.44 wig re-checked 5 Oct: watertight, 1 body, 624.9 cm³, fits; `FINAL_WIG_model_frame.stl` is skipped, it is not print-oriented) | watertight, 1 body, fits |
| `render_assembly.py` | — | 26 PNGs for [docs/assembly_guide.md](../../docs/assembly_guide.md) | — |

The logic of each script is copied unchanged from the original measurement scripts (`body-v3.34-body/measure/*`, `hair-v3.40/checks/*`). Only the loading changed: the scene npz instead of the Blender exports. That is why the results match the records exactly.

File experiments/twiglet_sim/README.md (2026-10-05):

# twiglet_sim: MuJoCo sims for the Twiglet robot

The default model is `models/twiglet_v3_v334_wig344.xml`: body v3.34 + head v3.30 + wig v3.44 (c14). It has 19 actuators (10 legs STS3215, 3 head STS3215, 6 arms STS3032) and weighs 2.753 kg, with the head at 0.814 kg. All sims run from this folder with plain relative paths.

```bash
pip install mujoco numpy
python run_tests.py v3                 # (a) standing, (b) push, (c) weight shift, (e) head + arm motion -> out/results_v3.json
python walk_eval.py v3                 # main gait, nominal + 20 randomized trials -> out/walk_v3.json
python walk_eval.py v3 --eff           # efficient gait -> out/walk_v3_eff.json
python walk_heldout.py v3 walk_v3_best.npy mytag   # held-out seeds 6000-6019 -> line in out/sim_summary.txt
./run_all.sh twiglet_v3_v334.xml v334     # tests + both gaits on any model in models/, logs in out/v334/
```

## Environment variables

| var | default | what |
|---|---|---|
| `TWIGLET_XML` | `twiglet_v3_v334_wig344.xml` | the model: a file name in `models/` or a path |
| `TWIGLET_OUT` | `out/` | where outputs go (gitignored). `run_all.sh` sets `out/<tag>` |
| `TWIGLET_PARAMS` / `TWIGLET_PARAMS_EFF` | `walk_v3_best.npy` / `walk_v3_eff_best.npy` | gait params: a file name in `params/` or a path |
| `TWIGLET_RESULTS` | `$TWIGLET_OUT/results_v3.json` | balance gains for `arm_heat.py` (from `run_tests.py`) |
| `PYTHON` | `python3` | interpreter used by `run_all.sh` |

No script writes into `models/`, `params/` or `results/`, and `run_all.sh` no longer copies the model anywhere. The old `twiglet_v3.xml` symlink is gone, so a run can no longer overwrite the model in `mini_bdx/robots/twiglet_v334/`.

## Files

| file | what |
|---|---|
| `simlib.py`, `episode.py` | model loading (`TWIGLET_XML`), STS3215/STS3032 servo models, soft joint limits, gait generator, balance feedback, metrics, episode runner |
| `run_tests.py` | (a) standing / COM window, (b) push recovery, (c) weight shift + single support, (e) head + arm motion (min support margin, peak torques incl. head pitch) |
| `walk_search.py` | gait parameterisation (12 params: `f, stride, lift, sway, sway_ph, crouch, lean, kp_pitch, kd_pitch, kp_roll, kd_roll, ank_off`), random search + CEM, robustness check |
| `walk_eval.py [--eff]` | nominal + 20 randomized 10 s walks (mass ±10 %, friction 0.6–1.0, armature, latency) |
| `walk_refine.py [--eff]` | local refine for a new body (24 perturbations × 10 seeds); writes `out/*_refined.npy`, never the shipped params |
| `walk_heldout.py` | 20 held-out seeds (6000–6019) |
| `arm_heat.py` | 30 s continuous arm waving at 0.5 / 0.8 / 1.5 Hz: RMS torque vs rated, copper loss |
| `diag_e.py` | test (e) alone with searched or fixed balance gains |
| `walk_video.py [--eff]` | GIF/MP4 + torque traces (needs an OpenGL backend, e.g. `MUJOCO_GL=egl`) |
| `quick_static.py` | quick standing check |
| `run_all.sh <model> <tag> [params] [params_eff]` | run_tests + both gaits; one summary line per run in `out/sim_summary.txt` |
| `walk_v3_best.npy` | main gait = `params/walk_v3_best_v334r1.npy` (v3.34 refine s35) |
| `walk_v3_eff_best.npy` | efficient gait = `params/walk_v3_eff_best_v333r1.npy` |
| `tools/` | `make_v334_wig.py` rebuilds the current model from `models/twiglet_v3_v334.xml` + the head inertial and collision box of a hair-series model (default `hair_c14_v344.xml` = wig v3.44; runs from the repo). Provenance only, because they need the original build workspace: `gen_mjcf_v3.py` (MJCF generator), `mass_v334.py` (mass/inertia from the meshes), `make_xml_variant.py` |

## models/ (52 MJCF files, all load, nu = 19)

`models/meshes` is a symlink to `../../../mini_bdx/robots/twiglet_v334/meshes`. The meshes are visual only and are the same for v3.32–v3.34. Contact is only the floor plane vs 4 boxes (trunk, both feet, head), so self-collision between parts is not simulated here; that is what `../twiglet_geom/` checks.

| group | files | what |
|---|---|---|
| current | `twiglet_v3_v334_wig344.xml` | body v3.34 + head v3.30 + wig v3.44 c14 (2.753 kg) |
| previous | `twiglet_v3_v334_wig340.xml` | the same with wig v3.40 (2.743 kg) |
| body versions | `twiglet_v3_body_v320.xml` … `twiglet_v3_body_v329.xml`, `twiglet_v3_v331c_head330.xml`, `twiglet_v3_v332.xml`, `twiglet_v3_v333.xml`, `twiglet_v3_v333g.xml`, `twiglet_v3_v334.xml` | each released body (v3.34 = 2.753 kg with the old fringe) |
| head/wig infill sweep (simC) | `twiglet_v3_head330{,rd,trim,trimF}_{0.0,0.02,0.03,0.045,0.06}.xml` | head v3.30 variants × wig infill; `head330rd_0.045` is the hair base and equals `v331c_head330` |
| rev studies | `twiglet_v3_revB1.xml`, `twiglet_v3_revC.xml`, `twiglet_v3_revC2.xml` | the v3.31 arm/body revisions |
| studies | `twiglet_v3_opt_neck40*.xml`, `twiglet_v3_s_armonly.xml`, `twiglet_v3_s_noarm.xml` | neck 40 mm shorter (+ legs); arm sensitivity |
| hair series | `hair_s16_v334.xml`, `hair_t15_v335.xml`, `hair_u5_v336.xml`, `hair_v6_v337.xml`, `hair_w9_v338.xml`, `hair_x5_v339.xml`, `hair_y2_v340.xml`, `hair_c14_v344.xml` | each wig candidate on the hair base body; y2 = wig v3.40, c14 = wig v3.44 |

## params/ (22 gait files)

`params/MANIFEST.json` lists every file's 12 values and where it came from. Current: `walk_v3_best_v334r1.npy` (= refine s35), `walk_v3_eff_best_v333r1.npy`. Also the v3.34 refine candidates s34 / s36, v333r1, v332r1/r2, v39, rev C, the v3.1 search results and the `*cur` snapshots.

## results/

| folder | what |
|---|---|
| `v334_wig344/` | ✅ re-run from this repo on 5 Oct 2026 with the current model (wig v3.44): `results_v3.json`, `walk_v3*.json`, logs, `heldout_v334r1.log`, `arm_heat_v3.json` |
| `v334_wig340/` | ✅ the previous model (wig v3.40), 4 Oct 2026: `results_v3.json`, `walk_v3*.json`, logs, `heldout_v334r1.log`, `arm_heat_v3.json` |
| `v334_repo/` | ✅ re-run from this repo of the v3.34 body (old fringe): reproduces the v3.34 record exactly |
| `sim_summary_repo_runs.txt` | the summary lines of those runs |
| `record_v334_r2/` | the original v3.34 record (r2 run, refine s34/s35/s36, held-out lines) |

| result | v3.34 record | v3.34 re-run here | v3.34 + wig v3.40 | v3.34 + wig v3.44 (current) |
|---|---|---|---|---|
| standing margin | 50.8 mm | 50.8 mm | 50.5 mm | 50.5 mm |
| e-margin (head + arm motion) | 34.0 mm | 34.0 mm | 34.4 mm | **34.1 mm** |
| head-pitch peak | 0.808 N·m (2.36× stall) | 0.808 | 0.796 N·m (2.40×) | **0.796 N·m (2.40×)** |
| head-pitch static hold (`quick_static.py`) | – | – | 0.2345 N·m (2.09× of 0.49) | **0.2323 N·m (2.11×)** |
| main gait, 20 randomized | 20/20, 0.208 m/s | 20/20, 0.208 | 20/20, 0.210 | **19/20, 0.206** |
| efficient gait | 20/20, 0.156 m/s | 20/20, 0.156 | 20/20, 0.156 | **20/20, 0.156** |
| held-out 6000–6019 | 19/20, 0.207 m/s | – | 19/20, 0.202 | **18/20, 0.206** |
| arm waving, shoulder RMS/rated | – | – | 0.87× / 1.04× / 1.70× | 0.87× at 0.5 Hz, 1.04× at 0.8 Hz, 1.70× at 1.5 Hz (identical) |

The older versions are in [`../history/sim_history.md`](../history/sim_history.md).

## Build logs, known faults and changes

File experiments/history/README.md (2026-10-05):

# history: archived results of every earlier version

This is a read-only archive. It holds the results of each design iteration, copied from the original build workspace so the numbers behind every decision are in the repo:
- `body-v2` … `body-v3.34-body`: per body version. `sim/` has results_v3.json, walk_v3*.json, compare_*.md, logs and the plots. The collision/measure json and the READMEs and print notes are also here.
- `hair-v3.33` … `hair-v3.41`: the wig iterations (IoU fits, arm/head checks, sims, STATUS logs).
- `head-v2`, `head-v3-digital-eyes`: the head designs before v3.30.
- `tmp_eye_c_head_agent`: the eye-coverage work for head v3.30.

What it contains:
- 1239 unique files (19 MB): json/txt/md/csv/log under 3 MB, the sim/simC PNG plots under 1.5 MB, and 18 short mp4 walk/push/head-arm videos (v2 to v3.2, each under 2 MB). There are no v3.3x videos.
- Exact duplicates (same md5) are stored once. [`INDEX.csv`](INDEX.csv) maps every original path (8408 rows) to the stored copy.
- Not archived: meshes, Blender files, renders, caches and the ~10 MB GIFs.

[`sim_history.md`](sim_history.md) / `.csv` is the per-version table (mass, standing margin, e-margin, head-pitch peak, gait success and speed). Rebuild it with `python ../tools/history_table.py`.

Some logs and notes in here (about 50 files) refer to the original build workspace as `$WORK/...` (the absolute paths were replaced by that placeholder). They document what was run; nothing in here is meant to run. The runnable versions are in `../twiglet_sim` and `../twiglet_geom`.

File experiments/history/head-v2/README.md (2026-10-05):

# Twiglet head A for the Open Duck Mini v2 (photo-accurate ball head)

This is head **A**, the one chosen: a 170 mm wood-grain ball with big black eye discs, orange rings, an offset tube snout, a yellow printed fringe and a black chin collar.
**The hat and the green kilt are FABRIC**, made by you, and are never printed. The ghost hat in the renders only shows where the felt goes, and the clearance checks include it inflated by 3 mm.
Variant B (the game-style head) is in `variant-b/`, but it is not part of this pack.

## Parts (all in `stl/`, print-oriented; the previous revision is in `stl_prev/`)

All parts are watertight single bodies and fit the Bambu P1S bed (256 mm).

| File `twiglet_head_v2_…` | Colour | Qty | Size mm | ~g | Orientation / supports |
|---|---|---|---|---|---|
| head_upper | wood brown PLA | 1 | 168×168×73 | 78 | Split-plane rim down. Tree supports inside the crown only. |
| head_lower | wood brown PLA | 1 | 169×170×66 | 148 | Deck down, neck opening up. Tree supports "on build plate only" for the snout collar and bearing pocket. |
| chin_collar_L / _R | **black** PLA | 1+1 | 144×72×11 | 7 each | Joint face down, no supports. This is the photo's dark collar. |
| eye_cup_L / _R | black / very dark brown | 1+1 | 67×67×9 | 20 each | Back down, no supports. |
| eye_ring_L / _R | translucent **orange** | 1+1 | 35×35×4.4 | 4 each | Flat back down. |
| snout | wood brown PLA | 1 | 61×61×71 | 42 | Mouth down, no supports. |
| fringe | **yellow** PLA | 1 | 108×240×129 | 75 | Forehead up. Tree supports under the hidden underside and the tips. |
| display_stand (optional) | any | 1 | 132×132×142 | 114 | Base down. |

- Robot head printed total: **≈405 g**. The stock printed head is ≈317 g.
- The mass assumes 3 walls and 15 % gyroid infill, with the shells effectively solid.
- See `renders/parts_sheet_A.png` for the true colours.

**Hardware**
- M3 heat-set inserts:
  - 4 in the copied roll-mount bosses;
  - 4 in the dome columns;
  - 4 radial ones in the collar tabs (Ø4×6).
- M3 screws: 4 for the mount, 4 for the dome, 4 for the collar (M3×8, radial).
- 4× M2.5 for the Pi (stock standoffs).
- 4× M2.5 for the relocated ODM board on top of the deck.
- Six 3 mm LEDs behind the rings (optional).
- 5 × 3 mm magnets and/or stitching for the hat.

## Assembly order (bench, head upside down, collar OFF)
1. Fit the inserts.
2. Glue each orange ring into its black cup, and each cup into its pocket in the dome.
   - Bend the LED leads short. The pocket behind each ring leaves ≈10 mm of depth.
3. Glue the snout spigot into the socket, keyed. **Glue it to head_lower only**; the dome lifts off freely (checked).
4. Press and glue the fringe's pegs into the holes below the hat line, on the dome.
5. Put the Pi Zero on its standoffs (3 screws go straight in; the one at (65, 60) needs a ~20° tilted driver).
6. Put the relocated board on top of the deck (4× M2.5).
7. Fix the head to the stock `head_roll_mount` with 4× M3, vertically from below.
   - The holes match the stock mesh to within 0.1 mm.
   - The stock bearing sits in the copied holder.
8. Close the dome with 4× M3 from below. Use a ball-end hex at ~15°.
9. The neck side screws (`head_pitch_to_yaw`, 8× along ±y) can all be reached straight on, **even with the collar fitted** (tool path checked with a 110 mm driver).
10. Fit the two black collar halves around the neck: 2 radial M3 per half, into the tab inserts.
11. **Cables:** route the head cable down the side of the neck, not the back.
    - At the collar opening (Ø122 at z 166) the radial gap is 17–29 mm at the sides.
    - At the back it is ~0, so don't route there.
    - The deck cut-outs pass the leads down from the Pi and the board.
12. Dropped from stock: `head_bot_sheet`, the antenna holders and the SG90 "ears".

**Fabric hat anchors** (fitted to the photo's brim line: front edge at el 70°, back at −10°):
- a groove ring marks the hem line;
- 5 × 3 mm magnet pockets;
- 4 × Ø2 stitch holes.
- The fringe root band sits under the brim, so the felt covers the fringe roots.

## Fit with the rest of the robot (checked; scripts in `fit/`)

- **Rest pose:** the head parts don't touch each other or the ODM (mount, roll servo, bearing, Pi, neck). The relocated board envelope is clear too. Minimum clearance 1.0 mm (head_lower vs head_yaw_to_roll).
- **Body change:** the shoulder axis was lowered 12 mm (z 84 → 72) and the shoulder-mount plate top trimmed (124 → 110).
  - Without this, the chin hit the shoulder mounts and servos when looking down.
  - The rest-pose checks of the whole robot are clean.
- **Head/neck sweep, 525 poses:**
  - Twiglet-only hard collisions (printed parts plus felt hat +3 mm) went from 60 to 10. All 10 remaining are at extreme yaw+roll+pitch combinations.
  - The stock head itself collides in 290 of these poses.
- **Soft limits** (URDF joint degrees): collision-free on a finer 3330-pose grid, and they keep 78 % of the poses where the stock head is clear:
  - |head_roll| ≤ 20°
  - neck_pitch + head_pitch ≥ −35° (no deep look-down onto the chest)
  - if |head_yaw| > 60°: head_pitch between −20° and +10°
  - if neck_pitch ≥ 40°: |head_yaw| ≤ 90°, and |roll| ≤ 10° when |yaw| > 45°
- **Arms:**
  - With the head neutral, the first contact is at shoulder-forward 105° (elbow 90°) to 135° (elbow 0°). Soft limit: shoulder forward ≤ 100°.
  - For walking, keep the elbows flexed ~90°. That gives 0 of 120 random gait poses colliding. With straight arms, 5 of 120 extreme gait samples touch fingers to foot or knee (it was 2 of 120 before the shoulder drop).
- **Felt hat tail:** it drapes onto the neck, back and shoulders in many poses (soft contact only). Keep the tail short and floppy, or tack it to the crown.

## Neck servo load (STS3215, 7.4 V, stall ≈1.91 N·m)
- Head assembly mass (bottom-up): stock ≈456 g → head A ≈583 g. That includes the servo, Pi, board, inserts and ~45 g of felt hat.
- The head's centre of mass moves ≈16 mm forward and 30 mm up.

| Joint | Stock worst | Head A worst | Head A margin |
|---|---|---|---|
| neck_pitch | 0.63 N·m (33 %) | 0.96 N·m (50 %) at neck 65 / head +45 | 1.98× stall |
| head_pitch | 0.27 N·m | 0.53 N·m (28 %) | 3.6× |
| head_roll | 0.03 N·m | 0.12 N·m (6 %) | 15× |

- At rest the load is 0.20 N·m (11 %).
- With neck + head pitch kept between −35° and +45°, neck_pitch stays ≤ 0.64 N·m (33 %, 3×).
- **No head scale-up is recommended.** At ×1.1 the neck_pitch worst case rises to ≈1.4 N·m (~74 % of stall), and the chest/shoulder clearance is lost.

## Proportions vs the photo
| | Photo | Model (head A on ODM + Twiglet body) |
|---|---|---|
| Head Ø / total height (no hat) | ~0.38 (0.41 raw, minus the camera-from-above bias) | **0.34** (170 / 503 mm) |
| Head Ø / total height (with hat) | 0.34 | 0.33 (170 / 517 mm) |
| Head Ø / shoulder width incl. arms | ~1.16 | 1.42 (arms 120 mm wide, in front of the torso) |
| Slim torso | yes | ODM trunk 110 mm wide |

The head is about "a third of the height", as intended.

## Fidelity vs the photo (camera matched: az +13°, el 15°; see `renders/compare_overlay_photo.png`)
| Feature | Photo | Before | Now |
|---|---|---|---|
| Eye disc / ball Ø | 0.41 | 0.31 | 0.39 |
| Eye azimuth / elevation | ±32° / ~19–20° | ±24° / 21° | ±32° / 19.5° |
| Ring OD / disc; pupil / disc | 0.52; 0.26 | 0.54; 0.32 | 0.52; 0.27 |
| Snout mouth OD / bore / lip | ≈61 / 45 / 8–9 mm | 46.8 / 31 / 7.9 | 61 / 45 / 8 |
| Snout axis (points to the viewer's left, slightly down) | photo fit | yaw 0, pitch −10 | yaw −28, pitch −8 |
| Mouth position (projected, units of R) | (−0.72, −0.64) | (−0.37, −0.64) | (−0.71, −0.63) |
| Fringe clumps / thickness | ~13–16, felt-thin | 11 / 12 mm | 15 / 7–7.5 mm |
| Side locks | to jaw level, viewer's right wider | short | to ~el −20°; viewer's right flares wider |
| Hat front edge | el ~70–75° | 54° | 70° |
| Dark collar | yes | none | black split collar |

## Honest mismatches
- The printed fringe is still more regular than felt strands. Dry-brush it, or overlay felt, for the photo look.
- The side-lock tips were shortened ~6° to clear the chest when the head yaws. The photo locks hang slightly lower.
- The photo shows the head sitting directly on the shoulders. On the ODM, ~40 mm of neck stack shows between the torso top and the collar. Suggestion: a black fabric neck gaiter, which is flexible and won't limit motion.
- The ODM body is not the photo body:
  - the legs are wide-set (239 mm);
  - the arms hang in front of the torso;
  - so the shoulders read narrower than the head (1.42 vs 1.16).
- Widening the arms beyond y ±60 would put the fingers into the legs during gait, so I didn't change it.
- The eye discs are flat printed bezels, not the photo's glossy domes.
- The ghost hat is indicative. Your real felt hat's tail length decides how often it drapes on the body.

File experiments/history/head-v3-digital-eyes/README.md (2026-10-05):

# Twiglet head A v3: digital eyes

This is head A v2 (`../head-v2/`, unchanged) with the printed eye cups, orange rings and LED holes replaced by **two 2.1" round 480×480 IPS screens**. The screens show orange pixel-art eyes on black, sit flat behind round black-rimmed openings, and switch instantly between expressions.

Everything that isn't eye-related is head A v2, rebuilt from `scripts/parts_head2_base.py` (a verbatim copy of `head-v2/parts_head2.py`):
- the 170 mm wood ball and split plane
- the snout
- the fringe
- the chin collar
- the ODM neck / roll mount interface
- the hat anchors (groove, magnets, stitch holes)
- the fringe pegs

front

## 1. Display choice

| | **Primary: Waveshare ESP32-S3-Touch-LCD-2.1** (flat, SKU 28169) | Backup: Waveshare ESP32-S3-(Touch-)LCD-1.85 |
|---|---|---|
| Panel | 2.1" round IPS, 480×480, ST7701S (16-bit RGB), CST820 touch (unused) | 1.85" round IPS, 360×360, ST77916 (QSPI) |
| Controller | ESP32-S3R8 on the back: 8 MB PSRAM, 16 MB flash, CH343 USB-UART | ESP32-S3R8, 8 MB PSRAM, 16 MB flash |
| Visible (active) area | **Ø53.9 mm** | ~Ø46 mm |
| Outline | Ø75.0 cover glass (0.7 mm), PCB 66.0 × 64.2 × 1.6 | ~55 × 55 mm |
| Depth | 9.5 mm from the glass front to the back of the standoffs (glass + LCD 3.4) | ~11 mm |
| Mounting | 4× M2 threaded standoffs on the back, Ø65 PCD, at (±29.5, +13.6) and (±18.0, −27.1) | 4× M2 |
| Connectors | 12-pin SH1.0 header at (+21.8, +21.8), 45°. 2× USB-C at (±23.6, −22.4), plugs pointing out along the 45° diagonals. TF slot. | SH1.0 UART/I2C, USB-C |
| Price | **US$32.99** each (US$31.79 for 1–9) at [Waveshare](https://www.waveshare.com/esp32-s3-touch-lcd-2.1.htm?sku=28169). **AU:** [Zaitronics](https://zaitronics.com.au/products/esp32-s3-development-board-with-2-1-round-capacitive-touch-display) US$42 (≈AU$63), 5–10 days. SpotPear US$39.90. Amazon AU B0DDPQSKJD was unavailable. Core Electronics doesn't stock it. | ~US$30–36 at [Waveshare](https://www.waveshare.com/esp32-s3-touch-lcd-1.85.htm) |
| Mass | not published; **~40 g estimated** from the STEP (glass + LCD + PCB) | ~25 g est. |

Dimensions come from Waveshare's drawing and STEP file (copies are in `ref/`) and the [wiki](https://www.waveshare.com/wiki/ESP32-S3-Touch-LCD-2.1).
- Do **not** buy the "2.1B": it has 2.5D curved glass.
- The backup would shrink the eye opening to ~46 mm. Its CAD is not done.

### Why this one
- **Look.** The video's orange pixel look is just pixel art. A 480×480 panel draws it with 12 px "LED dots" (1.35 mm pitch, 40×40 grid, 1 px rounded corners, 2 px black gaps). That matches the fine dot grid in the target photo far better than an 8×8 matrix, and it can show hearts, ^ ^, angry lids and blinks.
- **Size.** Ø53.9 mm active area against the photo-matched 58 mm opening. The 1.85" option would leave a 46 mm window.
- **Controller.** The ST7701 needs a 16-bit parallel RGB bus that the Pi Zero's SPI can't drive. Each board has its own ESP32-S3 on the back, so no separate eye controller is needed. The Pi sends short text commands over one UART line.
- **Tooling.** The official demo is Arduino IDE (esp32 core ≥ 3.0).

### Rejected
- **8×8 MAX7219 60 mm matrices** (~US$2–19): 8×8 is far too coarse for a ring, and a square module doesn't suit a round hole.
- **16×16 WS2812:** 160 mm, way too big.
- **GC9A01 1.28":** too small (Ø32 mm).
- **Round OLEDs:** ≤1.5".
- **Pi-driven SPI TFTs:** the Pi Zero would have to push both eyes, with no 2" round SPI option at this size.

## 2. Head changes (v2 → v3)

**Removed**
- `eye_cup_L/R` and `eye_ring_L/R`.
- The 6 LED holes.

**Kept**
- The v2 eye position: az ±32°, el 19.5°.
- The 67 mm black disc silhouette, so the fringe and photo match are unchanged.

**New parts**

| Part | What it is |
|---|---|
| `eye_bezel_L/R` (black PLA) | The visible black ring: 67 mm OD, flat face, 0.8 mm proud, same outline as v2's eye disc. **Round aperture Ø58 mm at the face**, 1 mm 45° chamfer to Ø56. Its back stops 0.3 mm in front of the cover glass (optional 0.3–0.5 mm black foam ring). Glued into `head_upper`. |
| `display_carrier_L/R` (PETG/PLA) | A ring behind the display's standoffs, with 4× M2 clearance holes and Ø4.4 × 1.5 counterbores. Has a notch for the 12-pin header and reliefs for USB-C plugs. A strut runs back to a foot plate that screws with **2× M3 down into two new posts on `head_lower`'s deck** (M3 heat-set inserts Ø4 × 6). Also has zip-tie slots and driver access holes for the M2 screws. |

**Where the screen sits**
- The screen is recessed **≈4.6 mm** behind the bezel face at the eye centre: 3.1 mm at the nearest rim point, 6.1 mm at the farthest.
- **That's deeper than the 2–4 mm asked for.** The limits are:
  - the Ø75 cover glass has to fit inside the 85 mm-radius, 3 mm-thick ball wall, with ≥1 mm of wood over the glass rim;
  - to clear the stock roll-mount bosses, the Pi Zero (L) and the snout spigot (R), the module axis sits at **az ±30°, el 21.5°**. That puts it **3.6 mm up/inward** of the eye's visual axis (hidden behind the bezel).
- The panel is tilted 0.7° so it can lift straight out without shaving the thin wood at the seam.
- The eye opening and its position are exactly as in v2.
- **Consequence:** the aperture isn't concentric with the active area. A thin crescent of the black non-active glass border shows on the lower-outer side (black on black, hardly visible).
  - The firmware centres the graphics on the aperture using a per-eye pixel offset.
  - The graphics are clipped to a 23 mm radius, so they never fall outside the active area.
- **Display rotation:** L is 90° and R is 180° in the CAD, so the 12-pin header points down/inward on both. The firmware compensates.

**Modified parts**

| Part | Change |
|---|---|
| `head_upper` (dome) | Holds the bezels. Has straight-up clearance cuts so it lifts off over the display pods. |
| `head_lower` | Two M3 posts per eye on the deck. Sockets for the glass and board, with straight-up clearance so each pod lifts out. A cable exit at the header. |
| `snout` | The internal spigot is trimmed where the R display sits. There's a 0.3 mm relief under the R bezel. The outside is unchanged. |

Unchanged: the fringe, chin collars, neck mount, hat anchors, roll bosses and Pi mounting.

**Checks** (`check_report.json`, `scripts/check_head3.py`, on the final grained build)

| Check | Result |
|---|---|
| Rest-pose interference: displays, carriers and bezels vs every head part and every ODM head-assembly part (Pi Zero, roll mount, servo, bearing…) | **0** |
| Display L to Pi Zero | min gap **0.6 mm** (tight; see caveats) |
| Dome lift, dome + fringe + bezels raised 0–80 mm | **0** |
| Pod service path (each pod lifted straight up 0–90 mm with the dome off) | **0** (0.04 mm³ at 1 mm on R, which is numerical noise) |
| Outer 0.8 mm skin compared with v2 | no new holes (one 0.9 mm³ seam sliver at (68, 69, 234), cosmetic; v2 had a similar 0.65 mm³ one) |
| All 10 printed parts watertight, single body, fit the P1S bed | **yes** (`build_report.json`) |

## 3. Mass

| | v2 | v3 |
|---|---|---|
| Printed head parts | 405 g (incl. eye cups 2×20 g + rings 2×4 g) | **382 g** (bezels 2×3 g, carriers 2×11 g) |
| Displays | 6 LEDs (~2 g) | **2 × ~40 g** (estimated) |
| Head assembly (servo, Pi, hat…) | 583 g | **≈653 g (+70 g)** |
| Worst neck_pitch moment | 0.96 N·m (50 % of STS3215 stall) | **1.08 N·m (56 %)** |
| Worst head_pitch | 0.53 N·m (28 %) | 0.61 N·m (32 %) |

The v3 numbers come from `torque_report.json`, using the same model as `head-v2/fit/torque.py`.

## 4. BOM additions

| Qty | Item | ≈Price |
|---|---|---|
| 2 | Waveshare **ESP32-S3-Touch-LCD-2.1** (flat, SKU 28169) | US$66 (Waveshare), or ≈AU$126 from Zaitronics |
| 8 | M2 × 5 pan/button-head screws (display to carrier) | <AU$3 |
| 4 | M3 × 8 socket-head screws + 4 M3 heat-set inserts (M3 × 4 × 5, Ø4 hole) | ~AU$3 |
| 2 | SH1.0 (JST-SH-compatible) 12-pin cable, ~150 mm. Check the box first; you only use 4 wires (GND, 5V, RX, TX), plus TX on the L board. | ~AU$5 |
| 1 | 4-pin inline connector (JST-XH/PH or DuPont) + ~30 cm of 26 AWG wire, to reach the Pi near the deck | ~AU$3 |
| opt | 0.3–0.5 mm black foam tape ring (75 mm OD / 56 mm ID) between the bezel and glass | ~AU$3 |
| — | Black PLA (bezels, ~6 g) + PETG/PLA (carriers, ~22 g) | — |

**Power:** each board takes 5 V on header pin 2 (VBus). Expect ~0.15–0.25 A each with orange-on-black at 80 % backlight (**not measured**). Budget 0.5 A total on the head's 5 V rail and check the ODM 5 V converter has the headroom alongside the Pi.

## 5. Wiring (Pi Zero 2W ↔ eyes)

```
Pi pin 8  GPIO14 TXD ──┬──> L board 12-pin #10 RXD (GPIO44)
                       └──> R board 12-pin #10 RXD (GPIO44)
Pi pin 10 GPIO15 RXD <──── L board 12-pin #9  TXD (GPIO43)     (R board TXD not connected)
Pi pin 6  GND ─────────── both boards pin #1 (or #5) GND
5 V rail ──────────────── both boards pin #2 VBus 5 V
```

**12-pin header**

| Pin | Signal |
|---|---|
| 1 | GND |
| 2 | VBus 5 V |
| 3 | D− / GPIO19 |
| 4 | D+ / GPIO20 |
| 5 | GND |
| 6 | 3V3 |
| 7 | SCL GPIO7 |
| 8 | SDA GPIO15 |
| 9 | TXD GPIO43 |
| 10 | RXD GPIO44 |
| 11 | NC |
| 12 | GPIO0 |

- **Pi setup:**
  - `raspi-config` → Serial: login shell **no**, hardware **yes**.
  - Add `dtoverlay=disable-bt` to `/boot/firmware/config.txt` so `/dev/serial0` is the PL011.
  - The ODM's servo bus runs over USB, so the GPIO UART is free.
  - The helper is `firmware/pi_eyes.py` (pyserial).
- **UART sharing:** GPIO43/44 are also wired to the board's "UART" USB-C port (CH343 through a mux). Unplug that USB-C when the Pi is driving the eyes.
- **Cable route:** the 12-pin header points down/inward through the carrier notch and the cable exit in `head_lower`. Run the cable along the deck to the Pi and zip-tie it through the carrier slots. Put the inline connector near the deck.

## 6. Firmware (`firmware/TwigletEyes/`)

`TwigletEyes.ino`, `st7701_panel.cpp/.h`, `eye_bitmaps.h` (generated by `scripts/eyes_art.py`) and `eye_geometry.h`. Both boards run the same sketch.

**Arduino IDE settings**
- Board: ESP32S3 Dev Module (esp32 core ≥ 3.0; tested to **compile** on 3.3.12)
- PSRAM: **OPI PSRAM**
- Flash: 16 MB; partition "16M Flash (3MB APP/9.9MB FATFS)"
- USB CDC On Boot: **Disabled**, so `Serial` is UART0 on the header and the UART USB-C
- Flash through the "UART" USB-C.

**Protocol:** 115200 8N1, one command per line, case-insensitive. Add `L:` or `R:` in front to address one eye.

| Command | Effect |
|---|---|
| `EYE ring` | default: thick orange ring, dark pupil, auto-blink |
| `EYE heart` | beating pixel heart |
| `EYE happy` | ^ ^ arch |
| `EYE angry` | ring with a lid slanted down toward the nose; mirrored per eye |
| `EYE wide` | surprised |
| `EYE blink` / `BLINK` | one blink: 7 frames × 55 ms |
| `EYE off` | backlight off |
| `EYE test` | calibration pattern |
| `LOOK x y` | x, y from −1 to 1. +x is toward the robot's own left, +y is up. Moves ±4 / ±3.5 dots. |
| `AUTOBLINK 0/1`, `BRIGHT 0..100`, `COLOR ff7a00` | settings |
| `SIDE L/R`, `ROT 0..3`, `MIRROR 0/1`, `CENTER x y`, `SAVE`, `INFO`, `PING`, `ECHO 0/1` | setup and diagnostics |

- Only the L board replies (`OK …`), because only its TX is wired back.
- Settings are saved to NVS with `SAVE`.
- Wi-Fi and BT are off.
- The ST7701 init sequence, pins and timings are ported from Waveshare's official demo.

**First-time setup per board**
1. Flash the sketch.
2. `SIDE L` (or `R`), then `SAVE`.
3. Install the board, send `EYE test`, and look through the opening:
   - The arrow must point up and the green dot must be on the viewer's right.
   - If it's wrong, adjust `ROT` / `MIRROR`.
   - Adjust `CENTER x y` until the grey circle sits concentric with the bezel.
4. `SAVE`.

The defaults in `eye_geometry.h` come from the CAD: L centre (218, 217), rot 2; R centre (263, 262), rot 3. **The panel's native scan orientation isn't documented, so treat these defaults as a starting point.**

## 7. Eye art (`eyes-art/`)

- `frames/*.png`: 480×480, as seen from the front, centred on the aperture.
  - Frames: ring, look_left/right/up/down, blink_0…6, happy, angry_L/angry_R (mirrored), heart, heart_small, wide.
  - Grid: 40 × 40 dots at a 12 px (1.35 mm) pitch.
  - Ring: OD 27 dots (36.7 mm, ~0.55 of the 67 mm eye disc, as in the photo); pupil 13 dots (17 mm).
  - Colour: #FF7A00 on pure black.
- `contact_sheet.png` shows all frames with the 56 mm aperture outline.
- `preview.gif` is a sequence on both eyes: ring → blink → look L/R → happy → angry → beating heart → wide → blink.
- The firmware uses the same bitmaps (`eye_bitmaps.h`), so the PNGs match what's drawn on the screen.

## 8. Assembly

1. Press the M3 inserts into the 4 deck posts on `head_lower` (the display posts).
2. Mount each display to its carrier with 4× M2 × 5 through the carrier ring into the board's standoffs. The carrier notch goes over the 12-pin header.
3. Plug in the 12-pin cable.
4. Drop each pod straight down into `head_lower`. The glass sits in its socket and the foot plate on the two posts. Fit 2× M3 × 8 from above.
5. Route the cables to the Pi along the deck. Zip-tie them through the carrier slots.
6. Glue the black bezels into `head_upper`'s eye openings (CA or epoxy): flat face out, flush 0.8 mm proud like v2. The optional foam ring goes on the bezel's back.
7. Fit the dome as in v2. It lowers straight down over the pods.

**Service:** remove the dome as in v2 (it lifts straight up with the bezels and fringe). Undo 2× M3, lift the pod straight out, and undo 4× M2 on the bench.

## 9. Print settings (Bambu P1S, 0.4 nozzle)

| Part | Material | Orientation | Supports |
|---|---|---|---|
| head_upper, head_lower, snout, fringe, collars | as in v2 (0.2 mm, 3 walls, 15 % gyroid) | as in v2 | as in v2. head_lower also needs "build plate only" tree supports under the display-post undersides. |
| eye_bezel_L/R | matte black PLA, 0.12–0.16 mm layers, 3 walls, 100 % | visible flat face down (smooth PEI gives a clean face) | none |
| display_carrier_L/R | PETG (or PLA), 0.2 mm, 4 walls, 40 % | ring front face (display side) down | tree supports under the foot plate |

## 10. Files

- `stl/twiglet_head_v3_*.stl`: 10 print-oriented parts.
- `build_report.json`: per-part size, mass, watertight, bed fit, colour, orientation.
- `check_report.json`: interference, dome-lift and pod-lift checks.
- `torque_report.json`
- `renders/`:
  - `head_front_ring.png`, `head_three_quarter_ring.png`, `head_front_ring_ghosthat.png`
  - `head_three_quarter_heart.png`, `head_three_quarter_happy.png`, `head_front_angry.png`
  - `compare_side_by_side_photo.png`
  - `exploded_eye_stack.png`, `section_L_eye.png`, `pod_rear_L.png`
  - `head_open_service.png`, `parts_sheet.png`
- `eyes-art/`: frames, contact sheet, GIF.
- `firmware/`:
  - `TwigletEyes/` Arduino sketch
  - `compile_log.txt`
  - `pi_eyes.py`
- `scripts/`:
  - `parts_head3.py` (model; run `python parts_head3.py --nograin` for a fast build)
  - `export_head3.py`, `check_head3.py`, `torque_head3.py`, `render_head3.py` (run with `xvfb-run -a`), `eyes_art.py`
  - `display_model.py` (Waveshare STEP geometry)
  - `parts_head2_base.py` / `render_head2_base.py` (copies of v2)
  - `dev/`: exploration scripts. They were written for the `scripts/` folder, so fix their paths before running them.
- `ref/`: Waveshare dimension drawing (PDF/PNG), tessellated STEP bodies, target photo crop.

**Env:** `$VENV` (trimesh + manifold3d + pyvista). The repo root must be on `sys.path`; the scripts handle this.

## 11. Not tested / caveats

- **No hardware yet.**
  - The firmware compiles, but it hasn't run on a board.
  - The panel's native orientation and exact centre offsets need calibrating with `EYE test`.
  - The mass (40 g per display) and current draw are estimates.
- **L display to Pi Zero:** 0.6 mm at the nearest point, which is tight. Check it on the first fit. If it rubs, the Pi can sit 1–2 mm lower on its standoffs, or `MOD_EL` can go up 0.5°.
- **Recess** is 3.1–6.1 mm (4.6 mm at the centre), against the 2–4 mm requested. A thin black glass-border crescent is visible at the lower-outer part of each opening (black on black).
- The Waveshare STEP is simplified: small parts are modelled as convex hulls grown by 0.4 mm. The **USB-C plug overmolds** are only relieved 0.8 mm into the carrier, so use the UART USB-C with the pod lifted out.
- Only the external surface is shared with v2, so the neck range-of-motion checks from v2 still apply. The eye changes are all inside the ball.

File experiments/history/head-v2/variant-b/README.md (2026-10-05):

# Twiglet head v2 - Variant B (game-style). Shared README (paths relative to head-v2/)

| | Variant A: photo-accurate (this folder) | Variant B: game-style (`variant-b/`) |
|---|---|---|
| Look | matches your robot photo: big round dark eye discs with orange LED rings, long tube snout, pale-mustard clumped fringe | closer to the Majora's Mask N64 Twiglet kid: angry slanted almond eyes with glowing yellow-orange inserts, short wide octagonal snout, flat olive-yellow leaf-blade fringe, strong vertical wood-grain ridges |
| Ball | Ø170 mm sphere, 2 mm wall, subtle ring grain around the snout | Ø170 mm sphere (+0.55 mm ridges), 2 mm wall, vertical grain ridges (5.5 mm pitch) |
| Snout | tube OD ≈47 mm, 58 mm long + thick lip, keyed spigot | octagon rim ≈81 mm across (≈48 % of face width), protrudes 36 mm, rounded octagon lip, black bore liner, keyed spigot |
| Printed parts | 8 (+ stand) | 9 (+ stand) |
| Est. printed head mass | ≈417 g | ≈436 g |
| Stock printed head (head.stl + head_bot_sheet + 2 antenna holders) | 317 g | 317 g |

Both variants share **the same internals**:
- **Neck mount:** the stock head's roll-mount region (4 insert bosses), roll-bearing holder and Pi Zero standoffs are copied from the official `head.stl` (Apache-2.0).
- **Deck and dome:** the same deck/dome split with 4× M3 insert columns.
- **Hat anchors:** the same fabric-hat groove ring, 5× Ø3 × 1.5 mm magnet pockets and 4× Ø2 stitch holes.
- **Fringe pegs:** the same 3 fringe peg holes.
- **Nothing printed for the hat or kilt.** Both are fabric. A hip ring for the skirt comes later.

## Files
- `stl/twiglet_head_v2_*.stl`: Variant A, print-oriented.
- `variant-b/stl/twiglet_head_v2B_*.stl`: Variant B.
- `build_report.json` / `variant-b/build_report.json`: per-part size, watertightness, volume, estimated mass, overhangs, colour, supports.
- `check_report.json` / `variant-b/check_report.json`: rest-pose interference plus a neck/head pose sweep vs the stock head.
- **Comparison sheets:**
  - `renders/compare_reference_vs_head_v2.png`: A vs your photo.
  - `variant-b/renders/compare_game_refs_vs_variant_b.png`: B vs the game images.
  - `renders/compare_A_vs_B.png`: A vs B.
- Other renders: `renders/head_*`, `display_*`, `odm_mounted_*` (A) and `variant-b/renders/headB_*`, `displayB_*`, `odmB_mounted_*` (B). A ghost hat is shown only in renders and is never exported.
- Scripts: `parts_head2.py`, `export_head2.py`, `render_head2.py`, `checks_head2.py [--variant-b]`, `make_compare.py`, `make_sheets.py`, `variant-b/{parts_head_b,export_b,render_b}.py`. Python 3 with trimesh, manifold3d, shapely and pyvista.

## Print settings (Bambu P1S, PLA/PETG)
- 0.2 mm layers, 3 walls, 15 % gyroid infill.
- Every part fits the 256 mm bed. The largest is a fringe at ≈195–203 mm.
- Orientation is baked into the STLs:
  - **Upper dome:** rim down, tree supports inside the crown.
  - **Lower shell:** deck down. Use tree supports "on build plate only" for the snout collar and the bearing pocket.
  - **Eye parts:** back down, no supports.
  - **Snout:** A goes mouth down; B goes rim down. No supports.
  - **B liner:** flange down.
  - **Fringe:** forehead up, with tree supports under the blade undersides and the tips.
- **Translucent orange/yellow filament** for A's rings and B's inserts lets the LEDs glow through.

## Assembly (both variants)
1. Heat-set the M3 inserts: 4 in the copied roll-mount bosses and 4 in the dome columns.
2. **Eyes:**
   - A: glue the orange ring into the black cup, route LEDs through the 3× Ø3.3 holes, then glue the cup into the shell pocket.
   - B: glue the translucent almond insert into the dark socket (2 LED holes), then glue the socket in.
3. **Snout:**
   - A: glue the spigot into the shell hole with the key aligned.
   - B: the same, then press or glue the black liner into the bore.
4. Press the fringe's 3 pegs into the holes under the hat line and glue them.
5. Put the Pi Zero on the copied standoffs. Mount the relocated board (it doesn't fit where the stock one sat) with 4× M2.5 on top of the deck. Close the dome onto the deck with 4× M3 from below.
6. Fit the head onto the stock head-roll servo mount. Use 4× M3 into the copied bosses, with the stock bearing in the copied holder.
7. **Dropped from stock:** `head_bot_sheet` (wider than the ball), the antenna holders, and the SG90 "ear" servos.
8. **Fabric hat:**
   - The groove ring sets the brim line.
   - Use 3 mm magnets in the pockets, or stitch through the Ø2 holes.
   - The hat's front edge tucks over the fringe.

**Display versions:** `*_display_stand.stl` bolts to the same 4 roll-mount bosses (4× M3 from below through the access tunnels). A has a round base; B has an octagonal one.

## Motion notes
See `check_report.json`. Avoid neck_pitch ≈65° combined with head_pitch −45°: the lower shell touches the neck sheets / body top there (set a soft limit). Sweep of 81 poses (roll ±30, yaw 0/±90, head_pitch ±45, neck_pitch −20/30/65): stock head 45 colliding poses; A 48 (6 Twiglet-only: 5 at neck 65 + head_pitch −45, 1 where A's long right fringe tip brushes the body top at yaw +90 / neck 30, 44 mm³, so limit yaw to about ±80° or trim that tip); B 48 (5 Twiglet-only, all at neck 65 + head_pitch −45). Rest pose: no interference for either.

## Known mismatches (honest)
**Variant A**
- The flat neck-opening underside shows in low views.
- The fringe is fewer, chunkier printed spikes, not felt strands. The real look needs felt or dry-brushing.
- The eye bezels are a clean printed disc, not the photo's glossy dome.

**Variant B**
- The game hair is darker olive with dark streaks and covers more of the crown and sides. B's 13 blades stop at the hat line and read brighter; paint the roots olive.
- The game head is a taller egg with no flat underside.
- The game eyes glow inside a black mask area. B's dark socket rim is only ≈4 mm.
- The game snout rim is a lighter tan-green. Print it in a lighter filament if you want that.

**Both**
- The head is ≈100–120 g heavier than the stock printed head.
- The ghost hat is a placeholder only.

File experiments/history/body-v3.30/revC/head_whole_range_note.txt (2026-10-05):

Whole printed head (shells, collars, snout, bezels, carriers, wig) vs trunk printed parts + arms (arms at rest), $WORK/tmp/eye/c/head_body_check.py + hb_fine.py
Neutral: 0 overlap volume vs every rev C trunk part (torso shells v331, frame/struts, chest leaves, kilt, hip ring/cradle) and upper-arm parts.
7x9x5 grid: 235/315 poses with some contact on rev C; v3.29 body baseline also 235/315 (same pairs) -> not a rev C regression.
Wig-only (the standing head-range metric): 4/315.
1-deg scans from level: roll first contact +/-10 deg (chin_collar_L/R x upper_arm_L/R); pitch +11 deg first contact head_lower x torso_shell_back; pitch -45 clean; yaw +/-160 clean at level.

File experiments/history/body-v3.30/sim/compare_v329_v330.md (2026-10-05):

| Metric | v3.29 | v3.30 |
|---|---|---|
| Total mass (kg) | 2.584 | 2.575 |
| Stands with no pre-lean | yes | yes |
| COM height (mm) | 246.7 | 246.4 |
| Support margin front / back / side (mm) | 56 / 46 / 70 | 55 / 47 / 70 |
| Tipping angle side / front (deg) | 15.9 / 12.8 | 15.9 / 12.5 |
| Static hip / knee / ankle N·m (x 0.49 rated) | 0.24 (0.49x) / 0.39 (0.79x) / 0.08 | 0.26 (0.52x) / 0.41 (0.83x) / 0.10 |
| Static neck pitch / head pitch N·m standing (x 0.49 rated) | 0.000 (0.00x) / 0.214 (0.44x) | 0.000 (0.00x) / 0.236 (0.48x) |
| Standing bus current (A) | 4.4 | 4.57 |
| Push survived, no controller F/B/L/R (N·s) | 1.34 / 1.10 / 1.69 / 1.69 | 1.29 / 1.15 / 1.64 / 1.64 |
| Push survived, IMU balance F/B/L/R (N·s) | 1.52 / 0.94 / 1.71 / 1.71 | 1.48 / 0.96 / 1.69 / 1.71 |
| Weight shift 0.4 Hz: min foot load at 0.15 / 0.20 rad | 0.00 / 0.00 | 0.07 / 0.00 |
| Walk max-speed: success (20 rand.) / speed / current | 100% / 0.210 m/s / 11.42 A | 100% / 0.209 m/s / 11.42 A |
| Walk energy-aware: success / speed / current | 100% / 0.162 m/s / 10.86 A | 100% / 0.160 m/s / 10.87 A |
| Head+arm test: fell / min margin / neck peak | no / 33.0 mm / n/a (no joint) N·m | no / 33.4 mm / n/a (no joint) N·m |
| Head+arm test peaks: head pitch / yaw / roll (N·m) | 0.789 / 0.78 / 0.386 | 0.802 / 0.778 / 0.383 |
| Arm wave worst RMS x rated 0.5 / 0.8 / 1.5 Hz | 0.76 / 1.01 / 1.66 | 0.76 / 1.01 / 1.66 |
| Arm wave max copper loss per servo W 0.5 / 0.8 / 1.5 Hz | 0.30 / 0.52 / 1.41 | 0.30 / 0.52 / 1.41 |
| Static shoulder gravity torque, straight arm, worst angle (N·m, x 0.147) | 0.066 (0.45x) | 0.066 (0.45x) |
| Fingertip payload continuous / brief (g), arm horizontal | 49 / 228 | 49 / 228 |
| Arm mass per side (g) | 99 | 99 |

Walks: nominal + 20 randomized 10 s trials (walk_eval.py). Arm-heat rows: arm links unchanged since v3.8 (arm_heat_v3.json carried over) (arm_heat_v3.json carried over).

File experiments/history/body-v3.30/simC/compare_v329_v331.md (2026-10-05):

| Metric | v3.29 | v3.31 |
|---|---|---|
| Total mass (kg) | 2.584 | 2.588 |
| Stands with no pre-lean | yes | yes |
| COM height (mm) | 246.7 | 246.7 |
| Support margin front / back / side (mm) | 56 / 46 / 70 | 56 / 46 / 70 |
| Tipping angle side / front (deg) | 15.9 / 12.8 | 15.9 / 12.8 |
| Static hip / knee / ankle N·m (x 0.49 rated) | 0.24 (0.49x) / 0.39 (0.79x) / 0.08 | 0.24 (0.49x) / 0.39 (0.79x) / 0.08 |
| Static neck pitch / head pitch N·m standing (x 0.49 rated) | 0.000 (0.00x) / 0.214 (0.44x) | 0.000 (0.00x) / 0.214 (0.44x) |
| Standing bus current (A) | 4.4 | 4.39 |
| Push survived, no controller F/B/L/R (N·s) | 1.34 / 1.10 / 1.69 / 1.69 | 1.34 / 1.10 / 1.69 / 1.69 |
| Push survived, IMU balance F/B/L/R (N·s) | 1.52 / 0.94 / 1.71 / 1.71 | 1.50 / 0.94 / 1.73 / 1.73 |
| Weight shift 0.4 Hz: min foot load at 0.15 / 0.20 rad | 0.00 / 0.00 | 0.07 / 0.00 |
| Walk max-speed: success (20 rand.) / speed / current | 100% / 0.210 m/s / 11.42 A | 95% / 0.213 m/s / 11.38 A |
| Walk energy-aware: success / speed / current | 100% / 0.162 m/s / 10.86 A | 100% / 0.163 m/s / 10.86 A |
| Head+arm test: fell / min margin / neck peak | no / 33.0 mm / n/a (no joint) N·m | no / 33.3 mm / n/a (no joint) N·m |
| Head+arm test peaks: head pitch / yaw / roll (N·m) | 0.789 / 0.78 / 0.386 | 0.789 / 0.78 / 0.386 |
| Arm wave worst RMS x rated 0.5 / 0.8 / 1.5 Hz | 0.76 / 1.01 / 1.66 | 0.76 / 1.01 / 1.66 |
| Arm wave max copper loss per servo W 0.5 / 0.8 / 1.5 Hz | 0.30 / 0.52 / 1.41 | 0.30 / 0.52 / 1.41 |
| Static shoulder gravity torque, straight arm, worst angle (N·m, x 0.147) | 0.066 (0.45x) | 0.066 (0.45x) |
| Fingertip payload continuous / brief (g), arm horizontal | 49 / 228 | 49 / 228 |
| Arm mass per side (g) | 99 | 99 |

Walks: nominal + 20 randomized 10 s trials (walk_eval.py). Arm-heat rows: arm servos/links unchanged; only +0.27 g leaf per shoulder (arm_heat_v3.json carried over) (arm_heat_v3.json carried over).

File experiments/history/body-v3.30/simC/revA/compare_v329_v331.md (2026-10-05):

| Metric | v3.29 | v3.31 |
|---|---|---|
| Total mass (kg) | 2.584 | 2.585 |
| Stands with no pre-lean | yes | yes |
| COM height (mm) | 246.7 | 246.7 |
| Support margin front / back / side (mm) | 56 / 46 / 70 | 56 / 46 / 70 |
| Tipping angle side / front (deg) | 15.9 / 12.8 | 15.9 / 12.8 |
| Static hip / knee / ankle N·m (x 0.49 rated) | 0.24 (0.49x) / 0.39 (0.79x) / 0.08 | 0.24 (0.49x) / 0.39 (0.79x) / 0.08 |
| Static neck pitch / head pitch N·m standing (x 0.49 rated) | 0.000 (0.00x) / 0.214 (0.44x) | 0.000 (0.00x) / 0.214 (0.44x) |
| Standing bus current (A) | 4.4 | 4.4 |
| Push survived, no controller F/B/L/R (N·s) | 1.34 / 1.10 / 1.69 / 1.69 | 1.34 / 1.10 / 1.69 / 1.69 |
| Push survived, IMU balance F/B/L/R (N·s) | 1.52 / 0.94 / 1.71 / 1.71 | 1.52 / 0.94 / 1.71 / 1.71 |
| Weight shift 0.4 Hz: min foot load at 0.15 / 0.20 rad | 0.00 / 0.00 | 0.00 / 0.00 |
| Walk max-speed: success (20 rand.) / speed / current | 100% / 0.210 m/s / 11.42 A | 100% / 0.208 m/s / 11.42 A |
| Walk energy-aware: success / speed / current | 100% / 0.162 m/s / 10.86 A | 100% / 0.162 m/s / 10.87 A |
| Head+arm test: fell / min margin / neck peak | no / 33.0 mm / n/a (no joint) N·m | no / 33.0 mm / n/a (no joint) N·m |
| Head+arm test peaks: head pitch / yaw / roll (N·m) | 0.789 / 0.78 / 0.386 | 0.789 / 0.78 / 0.386 |
| Arm wave worst RMS x rated 0.5 / 0.8 / 1.5 Hz | 0.76 / 1.01 / 1.66 | 0.76 / 1.01 / 1.66 |
| Arm wave max copper loss per servo W 0.5 / 0.8 / 1.5 Hz | 0.30 / 0.52 / 1.41 | 0.30 / 0.52 / 1.41 |
| Static shoulder gravity torque, straight arm, worst angle (N·m, x 0.147) | 0.066 (0.45x) | 0.066 (0.45x) |
| Fingertip payload continuous / brief (g), arm horizontal | 49 / 228 | 49 / 228 |
| Arm mass per side (g) | 99 | 99 |

Walks: nominal + 20 randomized 10 s trials (walk_eval.py). Arm-heat rows: arm servos/links unchanged; only +0.27 g leaf per shoulder (arm_heat_v3.json carried over) (arm_heat_v3.json carried over).

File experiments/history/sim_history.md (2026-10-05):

# Sim history per body version (from the archived results_v3.json / walk_v3*.json; generated by tools/history_table.py)

Each row is the LAST results_v3.json / walk_v3*.json written in that version's sim folder, so a row can be a side study rather than the release run (body-v3.32: the last write was a study run, its release run is v332_r2 in the v3.32 sim_summary.txt: 20/20 main, 20/20 eff). The release-run lines for v3.32-v3.34 are in history/body-v3.3x-body/sim/sim_summary.txt.

| version | total_mass_kg | stand_margin_mm | e_margin_mm | head_pitch_peak_Nm | main_succ | main_speed | eff_succ | eff_speed |
|---|---|---|---|---|---|---|---|---|
| body-v2 | 2.419 | 24.5 | 30.1 | 0.421 | 1.0 | 0.0786 | 0.95 | 0.0499 |
| body-v3 | 2.173 | 47.0 | 33.7 | 0.431 | 1.0 | 0.168 | 1.0 | 0.1326 |
| body-v3.1 | 2.213 | 49.3 | 29.3 | 0.423 | 1.0 | 0.1718 | 1.0 | 0.1372 |
| body-v3.5 | 2.184 | 46.8 | 32.4 | 0.542 | 1.0 | 0.1707 | 1.0 | 0.1429 |
| body-v3.10 | 2.424 | 50.2 | 33.1 | 0.725 | 1.0 | 0.1686 | 1.0 | 0.143 |
| body-v3.11 | 2.419 | 50.7 | 33.4 | 0.722 | 1.0 | 0.1696 | 1.0 | 0.144 |
| body-v3.12 | 2.423 | 50.2 | 33.1 | 0.725 | 1.0 | 0.1716 | 1.0 | 0.1426 |
| body-v3.13 | 2.439 | 50.6 | 34.9 | 0.731 | 1.0 | 0.1751 | 1.0 | 0.1435 |
| body-v3.14 | 2.486 | 50.4 | 26.6 | 0.779 | 1.0 | 0.1784 | 1.0 | 0.1442 |
| body-v3.15 | 2.522 | 50.3 | 17.9 | 0.825 | 1.0 | 0.1779 | 1.0 | 0.1474 |
| body-v3.16 | 2.518 | 48.8 | 30.6 | 0.749 | 1.0 | 0.1817 | 1.0 | 0.1522 |
| body-v3.17 | 2.547 | 48.6 | 33.6 | 0.771 | 1.0 | 0.1814 | 1.0 | 0.15 |
| body-v3.18 | 2.537 | 48.2 | 32.7 | 0.761 | 1.0 | 0.1821 | 1.0 | 0.1498 |
| body-v3.19 | 2.54 | 47.7 | 33.3 | 0.755 | 1.0 | 0.1775 | 1.0 | 0.1485 |
| body-v3.20 | 2.533 | 47.8 | 32.7 | 0.751 | 1.0 | 0.1816 | 1.0 | 0.149 |
| body-v3.21 | 2.534 | 48.4 | 33.0 | 0.756 | 1.0 | 0.1955 | 1.0 | 0.1467 |
| body-v3.22 | 2.547 | 47.7 | 33.0 | 0.763 | 1.0 | 0.1986 | 1.0 | 0.1491 |
| body-v3.23 | 2.568 | 48.2 | 33.2 | 0.797 | 1.0 | 0.1953 | 1.0 | 0.1624 |
| body-v3.24 | 2.556 | 47.7 | 32.1 | 0.764 | 1.0 | 0.197 | 1.0 | 0.1614 |
| body-v3.25 | 2.575 | 47.3 | 32.4 | 0.774 | 1.0 | 0.2001 | 1.0 | 0.163 |
| body-v3.26 | 2.561 | 47.8 | 32.9 | 0.757 | 0.95 | 0.2062 | 1.0 | 0.1602 |
| body-v3.27 | 2.575 | 48.3 | 32.5 | 0.772 | 1.0 | 0.2128 | 1.0 | 0.1607 |
| body-v3.28 | 2.587 | 49.0 | 33.3 | 0.79 | 1.0 | 0.2097 | 1.0 | 0.1618 |
| body-v3.29 | 2.584 | 49.2 | 33.0 | 0.789 | 1.0 | 0.2097 | 1.0 | 0.162 |
| body-v3.30 | 2.575 | 50.6 | 33.4 | 0.802 | 1.0 | 0.2086 | 1.0 | 0.16 |
| body-v3.31-body | 2.607 | 48.7 | 33.1 | 0.789 | 0.95 | 0.2097 | 1.0 | 0.1618 |
| body-v3.32-body | 2.754 | 41.2 | 32.0 | 0.835 | 0.85 | 0.1159 | 1.0 | 0.0998 |
| body-v3.33-body | 2.725 | 50.9 | 33.8 | 0.811 | 1.0 | 0.1929 | 1.0 | 0.1563 |
| body-v3.34-body | 2.753 | 50.8 | 34.0 | 0.808 | 1.0 | 0.2083 | 1.0 | 0.156 |

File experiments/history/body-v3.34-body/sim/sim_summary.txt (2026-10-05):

v334_r1 e None 34.0 {'head_pitch': 0.808, 'head_yaw': 0.779, 'head_r | succ 0.95 | eff succ 1.0
heldout v334_heldout_v333r1 params=walk_v3_best_v333r1.npy seeds6000-6019 succ 0.95 (19/20) speed 0.187
heldout v334_heldout_v334s34 params=walk_v3_best_v334s34.npy seeds6000-6019 succ 0.85 (17/20) speed 0.183
heldout v334_heldout_v334s35 params=walk_v3_best_v334s35.npy seeds6000-6019 succ 0.95 (19/20) speed 0.207
heldout v334_heldout_v334s36 params=walk_v3_best_v334s36.npy seeds6000-6019 succ 0.90 (18/20) speed 0.201
v334_r2 e None 34.0 {'head_pitch': 0.808, 'head_yaw': 0.779, 'head_r | succ 1.0 | eff succ 1.0

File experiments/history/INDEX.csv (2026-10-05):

source_path (relative to the build workspace dir) | md5 | bytes | stored_as (duplicates point at the first copy)
body-v2/README.md | ba2463858e1db16ffcf3d088a7d6525d | 7664 | body-v2/README.md
body-v2/build_report.json | ac023d3c078bfc5bc4c8169b0595d431 | 3321 | body-v2/build_report.json
body-v2/collide_report.json | a3a3d5b93bea9f16ac753d9fc3826842 | 7730 | body-v2/collide_report.json
body-v2/sim/README.md | af585876cc3c786c72e600276c9b7c32 | 6196 | body-v2/sim/README.md
body-v2/sim/mass_report_opt1.json | f5c5b6606749eb1693d01ba833d6139c | 12050 | body-v2/sim/mass_report_opt1.json
body-v2/sim/mass_report_stock.json | be054253ed8f674d57a6df952c9e26d3 | 10660 | body-v2/sim/mass_report_stock.json
body-v2/sim/mass_report_v2.json | 1f783a649066b8e091bb5fe3d0998e7c | 11874 | body-v2/sim/mass_report_v2.json
body-v2/sim/plot_stability.png | 6baea14b3af5576c9bde32ab6a61a6ff | 54645 | body-v2/sim/plot_stability.png
body-v2/sim/plot_trace_stock.png | bf42955a5e327d9d259b7e526d146009 | 244101 | body-v2/sim/plot_trace_stock.png
body-v2/sim/plot_trace_v2.png | 91774e02b78d2b458ea19599a3b62c63 | 193112 | body-v2/sim/plot_trace_v2.png
body-v2/sim/plot_walk_torque.png | bc82e433356bbb12efe922cb4123936f | 67080 | body-v2/sim/plot_walk_torque.png
body-v2/sim/plot_weight_shift.png | a075c9ff5e2323119b2dcb75b70e5d73 | 43402 | body-v2/sim/plot_weight_shift.png
body-v2/sim/push_recovery_stock.mp4 | 157881266e2486b770bbb9d327f66e12 | 330639 | body-v2/sim/push_recovery_stock.mp4
body-v2/sim/push_recovery_v2.mp4 | 4340ba1be64b8e2bb54f53a37ca23309 | 488633 | body-v2/sim/push_recovery_v2.mp4
body-v2/sim/results_opt1.json | 62080f7f5f610e24216d28a886c55897 | 7834 | body-v2/sim/results_opt1.json
body-v2/sim/results_stock.json | 1d1e8444f4496dab8e0afcb04a41e526 | 7639 | body-v2/sim/results_stock.json
body-v2/sim/results_v2.json | 5ac079d52ac977a93ad9c78c017f825a | 8068 | body-v2/sim/results_v2.json
body-v2/sim/sensitivity_v2.json | 844bc88a552e8589295df67c5a035025 | 2359 | body-v2/sim/sensitivity_v2.json
body-v2/sim/walk_stock.json | af49bfecbac439cb5d7968201b46ed72 | 2910 | body-v2/sim/walk_stock.json
body-v2/sim/walk_stock.mp4 | dffe8eeff6ef8093df22511f2fe49d61 | 825498 | body-v2/sim/walk_stock.mp4
body-v2/sim/walk_stock_eff.json | 66cd638ff73eca24d71c18a83bb9139c | 2910 | body-v2/sim/walk_stock_eff.json
body-v2/sim/walk_stock_eff.mp4 | 7d3ce52dde5899b1bf1f32d3bea73ee5 | 804698 | body-v2/sim/walk_stock_eff.mp4
body-v2/sim/walk_v2.json | 78d363b0cef3b6fdfe3c965c58b8524c | 3342 | body-v2/sim/walk_v2.json
body-v2/sim/walk_v2.mp4 | d63a00aada2af0ce0719c10c1d8d95f3 | 934937 | body-v2/sim/walk_v2.mp4
body-v2/sim/walk_v2_eff.json | 91f4c201bc10719369bc946077fed175 | 3358 | body-v2/sim/walk_v2_eff.json
body-v2/sim/walk_v2_eff.mp4 | 743b426b97a1fd53c268a650e7bf9ae8 | 864232 | body-v2/sim/walk_v2_eff.mp4
body-v3/README.md | d5dfb182350ce2de808eda08cc549acc | 8398 | body-v3/README.md
body-v3/build_report.json | 9b61b0593017977b40a0fa0bb4b44977 | 9420 | body-v3/build_report.json
body-v3/collide_report.json | 139d47ead7e99b3e4f3d8f96d37be113 | 33632 | body-v3/collide_report.json
body-v3/servo_choice.md | 21c463a0f09c46a1cb40f84fa5147d3c | 5952 | body-v3/servo_choice.md
body-v3/measure/photo_measure.json | 5832cf5aab493edae31cd598e050fc53 | 2746 | body-v3/measure/photo_measure.json
body-v3/measure/targets.json | 7b665a9c4ecd33771be6d5312f1cfcdb | 5282 | body-v3/measure/targets.json
body-v3/sim/README.md | 460e0f4d31c9d2942b29aa73734df930 | 7316 | body-v3/sim/README.md
body-v3/sim/arm_heat_v2.json | bc311c1775b81c9405219b9bbff5ec13 | 4223 | body-v3/sim/arm_heat_v2.json
body-v3/sim/arm_heat_v3.json | 24f0f1621b09d575497b233327d5af34 | 4223 | body-v3/sim/arm_heat_v3.json
body-v3/sim/compare_stock_v2_v3.json | 0ed3b329d48797a6244eeffa2d5fde08 | 3805 | body-v3/sim/compare_stock_v2_v3.json
body-v3/sim/compare_stock_v2_v3.md | 895225c90e71fdfa98f1516ec893a8b1 | 2949 | body-v3/sim/compare_stock_v2_v3.md
body-v3/sim/head_arms_v3.mp4 | 85f9b07588a6746c061c19cbc60dc55f | 174196 | body-v3/sim/head_arms_v3.mp4
body-v3/sim/mass_report_v3.json | ff65dbd84a68ba5e0bb13abda2d396d2 | 12532 | body-v3/sim/mass_report_v3.json
body-v3/sim/plot_compare.png | 2457a623d2f320f37f590b6d2c9af28b | 58887 | body-v3/sim/plot_compare.png
body-v3/sim/push_recovery_v3.mp4 | d4d3438c20a0ac395cfb1c8b8ce1a26f | 433255 | body-v3/sim/push_recovery_v3.mp4
body-v3/sim/results_v3.json | e91a5d8c46c37b6547966407c5d77848 | 8025 | body-v3/sim/results_v3.json
body-v3/sim/walk_v3.json | f6dfc33626937c34a72b551e33684da3 | 3337 | body-v3/sim/walk_v3.json
body-v3/sim/walk_v3.mp4 | 41bfc399374a0884fe14f7709a62ec52 | 924363 | body-v3/sim/walk_v3.mp4
body-v3/sim/walk_v3_eff.json | 394deba9fbf961cf5d88aae40d78c2e6 | 3347 | body-v3/sim/walk_v3_eff.json
body-v3/sim/walk_v3_eff.mp4 | ee76d2061b547ce4dfd893953c79e40f | 976749 | body-v3/sim/walk_v3_eff.mp4
body-v3.1/README.md | 62cf5740b1281b505a1e2bb98d536030 | 8478 | body-v3.1/README.md
body-v3.1/README_v3.md | d5dfb182350ce2de808eda08cc549acc | 8398 | body-v3/README.md
body-v3.1/build_report.json | f676bb3d55fd54df78b77a8a42d50ddb | 12106 | body-v3.1/build_report.json
body-v3.1/collide_report.json | a18cac6ca4a8a34e14263b9e0c332dfb | 28494 | body-v3.1/collide_report.json
body-v3.1/collide_v31_rule_check.json | 2cfb89f60ed078067a5b0d563369f90c | 129 | body-v3.1/collide_v31_rule_check.json
body-v3.1/servo_choice.md | 316473d63f90ad6a5649462db90ee4c3 | 7062 | body-v3.1/servo_choice.md
body-v3.1/measure/photo_measure.json | 5832cf5aab493edae31cd598e050fc53 | 2746 | body-v3/measure/photo_measure.json
body-v3.1/measure/targets.json | 7b665a9c4ecd33771be6d5312f1cfcdb | 5282 | body-v3/measure/targets.json
body-v3.1/measure/v31_measure.json | 7770567faa6c6ee5ce5e18b1da51c474 | 1121 | body-v3.1/measure/v31_measure.json
body-v3.1/sim/README.md | f9a64dca32a373016e65b29e999b8e4e | 10250 | body-v3.1/sim/README.md
body-v3.1/sim/arm_heat_v2.json | bc311c1775b81c9405219b9bbff5ec13 | 4223 | body-v3/sim/arm_heat_v2.json
body-v3.1/sim/arm_heat_v3.json | 2126fcc62fd7d3c396dcb7770419204a | 4220 | body-v3.1/sim/arm_heat_v3.json
body-v3.1/sim/compare_stock_v2_v3.json | 0ed3b329d48797a6244eeffa2d5fde08 | 3805 | body-v3/sim/compare_stock_v2_v3.json
body-v3.1/sim/compare_stock_v2_v3.md | 895225c90e71fdfa98f1516ec893a8b1 | 2949 | body-v3/sim/compare_stock_v2_v3.md
body-v3.1/sim/compare_v3_v31.json | 7e29f9219c9b23c6c5982ab3a1a89db3 | 2829 | body-v3.1/sim/compare_v3_v31.json
body-v3.1/sim/compare_v3_v31.md | 175081c021dce15c7e987872af0ac43f | 1611 | body-v3.1/sim/compare_v3_v31.md
body-v3.1/sim/mass_report_v3.json | b22177cef249a8bc99fcb2f57bb05878 | 12902 | body-v3.1/sim/mass_report_v3.json
body-v3.1/sim/plot_compare.png | 2457a623d2f320f37f590b6d2c9af28b | 58887 | body-v3/sim/plot_compare.png
body-v3.1/sim/results_v3.json | 510d1456468455e8152b440555672307 | 8029 | body-v3.1/sim/results_v3.json
body-v3.1/sim/v31_head_arms_v3.mp4 | 48a7d3e494eb7931d9cf1ae21757dc2d | 158269 | body-v3.1/sim/v31_head_arms_v3.mp4
body-v3.1/sim/v31_push_recovery_v3.mp4 | 3ab9571e7c6a56d8814a84cbb6aa1c72 | 381814 | body-v3.1/sim/v31_push_recovery_v3.mp4
body-v3.1/sim/v31_walk_v3.mp4 | f8b129b2c60318bb3e51ceb73bc7391b | 956000 | body-v3.1/sim/v31_walk_v3.mp4
body-v3.1/sim/v31_walk_v3_eff.mp4 | 854d3e13fb48f5733b015b48fa7595c0 | 983294 | body-v3.1/sim/v31_walk_v3_eff.mp4
body-v3.1/sim/walk_v3.json | 21a198ab40b540b4e3398bd7bdd66988 | 3094 | body-v3.1/sim/walk_v3.json
body-v3.1/sim/walk_v3_eff.json | 031ec90a823c37124efb0f9b271545e0 | 3102 | body-v3.1/sim/walk_v3_eff.json
body-v3.1/sim/v3_ref/arm_heat_v3.json | 24f0f1621b09d575497b233327d5af34 | 4223 | body-v3/sim/arm_heat_v3.json
body-v3.1/sim/v3_ref/results_v3.json | e91a5d8c46c37b6547966407c5d77848 | 8025 | body-v3/sim/results_v3.json
body-v3.1/sim/v3_ref/walk_v3.json | f6dfc33626937c34a72b551e33684da3 | 3337 | body-v3/sim/walk_v3.json
body-v3.1/sim/v3_ref/walk_v3_eff.json | 394deba9fbf961cf5d88aae40d78c2e6 | 3347 | body-v3/sim/walk_v3_eff.json
body-v3.10/README.md | 65c2e177b5412a5e63ba38b5190edbde | 6101 | body-v3.10/README.md
body-v3.10/README_v3.md | d5dfb182350ce2de808eda08cc549acc | 8398 | body-v3/README.md
body-v3.10/README_v31.md | 62cf5740b1281b505a1e2bb98d536030 | 8478 | body-v3.1/README.md
body-v3.10/README_v310.md | 8da2f237ff36b44d0add847660514f13 | 3734 | body-v3.10/README_v310.md
body-v3.10/README_v32.md | 36d5079dfd7d10c4ca271706c936cf5a | 12057 | body-v3.10/README_v32.md
body-v3.10/README_v33.md | 6752bb01dae32e530a285e330f4d5770 | 5164 | body-v3.10/README_v33.md
body-v3.10/README_v34.md | b512057a38e8cd7dd3ee07219c058e51 | 2623 | body-v3.10/README_v34.md
body-v3.10/README_v35.md | 7d8c481c42edc18f57b68b7bcea44345 | 2418 | body-v3.10/README_v35.md
body-v3.10/README_v36.md | 756af93fbf80b2ee9e5fee1458509d98 | 2438 | body-v3.10/README_v36.md
body-v3.10/README_v38.md | ed0092856c928668efe6274c4752d7c2 | 4651 | body-v3.10/README_v38.md
body-v3.10/README_v39.md | 93f974e23db0965ce50120ba22d3dfaf | 4818 | body-v3.10/README_v39.md
body-v3.10/bom_v35.md | 54e414cced6d75762caa12cba76d0d40 | 1012 | body-v3.10/bom_v35.md
body-v3.10/build_report.json | 3c08239c078593b51d293cace8ec1a27 | 19929 | body-v3.10/build_report.json
body-v3.10/changed_parts_v36_to_v37.json | a9a41d7c46a2ad62fed49408f90e4b29 | 1338 | body-v3.10/changed_parts_v36_to_v37.json
body-v3.10/changed_parts_v37_to_v38.json | 49ae233dc0c85f386397a6f0a52f4f9a | 6172 | body-v3.10/changed_parts_v37_to_v38.json
body-v3.10/changed_parts_v38_to_v39.json | d3cd5cdf0f50ea6407e39f2225cef809 | 6381 | body-v3.10/changed_parts_v38_to_v39.json
body-v3.10/collide_head_v310.json | e25c6464886e09f567ee551e6f338f74 | 2142 | body-v3.10/collide_head_v310.json
body-v3.10/collide_log_v38.txt | 9401ea726b306a56955aecbaf3d6525e | 4281 | body-v3.10/collide_log_v38.txt
body-v3.10/collide_log_v39.txt | 9401ea726b306a56955aecbaf3d6525e | 4281 | body-v3.10/collide_log_v38.txt
body-v3.10/collide_report.json | e6ddd4078834a837f9559a91643465bb | 20690 | body-v3.10/collide_report.json
body-v3.10/collide_v31_rule_check.json | 2cfb89f60ed078067a5b0d563369f90c | 129 | body-v3.1/collide_v31_rule_check.json
body-v3.10/collide_v32_rule_check.json | 005b67a629f7dd1569344a87c0e8df7b | 164 | body-v3.10/collide_v32_rule_check.json
body-v3.10/grain_report_v37.json | a597b4bb4e221a831841bdb135646a29 | 1959 | body-v3.10/grain_report_v37.json
body-v3.10/head_print_report.json | 79f615cf398723aa2801b3336ef39415 | 6972 | body-v3.10/head_print_report.json
body-v3.10/head_print_report_v36.json | d33da0d7f147f0bd784709823ca6e9ae | 7037 | body-v3.10/head_print_report_v36.json
body-v3.10/head_print_report_v37.json | 4e0e79baf232a56165080655c08ae618 | 7733 | body-v3.10/head_print_report_v37.json
body-v3.10/head_print_report_v38.json | 5d6e16e5fb2414e0bbfca34176d0c3f5 | 7735 | body-v3.10/head_print_report_v38.json
body-v3.10/head_print_report_v39.json | ba2c678786c8b3f4cd8feca3787e75dd | 7781 | body-v3.10/head_print_report_v39.json
body-v3.10/head_size_v36.json | 04f54b55f682598962ff3481a5aba85f | 717 | body-v3.10/head_size_v36.json
body-v3.10/print_note_snout_v310.md | 8c28ce33c8014e2a35235021cfe421d2 | 1461 | body-v3.10/print_note_snout_v310.md
body-v3.10/print_sheet_body_v38.md | face3494b2f0898c92d4de88aa098edc | 6733 | body-v3.10/print_sheet_body_v38.md
body-v3.10/print_sheet_head.md | ac0500e69043b84dbd57f7204b995982 | 3511 | body-v3.10/print_sheet_head.md
body-v3.10/print_sheet_head_v36.md | 6ac4c2094ed80fd60fd094d5b6ead7f8 | 3683 | body-v3.10/print_sheet_head_v36.md
body-v3.10/print_sheet_head_v37.md | e9fbab93227e450a8c099f93fd6ea65b | 5234 | body-v3.10/print_sheet_head_v37.md
body-v3.10/print_sheet_head_v38.md | 1bd44b955d22ea2e13d00bf05d107d31 | 5698 | body-v3.10/print_sheet_head_v38.md
body-v3.10/print_sheet_head_v39.md | be1e14d15b9f562fb02da2a9853dbef9 | 5766 | body-v3.10/print_sheet_head_v39.md
body-v3.10/servo_choice.md | 316473d63f90ad6a5649462db90ee4c3 | 7062 | body-v3.1/servo_choice.md
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

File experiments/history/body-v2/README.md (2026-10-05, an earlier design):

# Twiglet body v2 (option 2: photo-accurate)

This is a new body for the ODM humanoid. It gives Twiglet narrow hips, legs directly under a slim wood-brown torso, arms hanging at his sides, and **head A unchanged** on top. The hat and kilt are fabric.

It uses the same 20 × STS3215 servos and the same electronics as the stock ODM. The stock leg links, arm links, fingers and boots are reused. All earlier parts are left untouched; the new parts are the `v2_*` files.

Renders are in `renders/`. The comparison sheet is `renders/compare_photo_current_opt1_opt2.png` (reference photo, current build, option 1, option 2). The simulation is described in `sim/README.md`.

## New printed parts (`stl/`)
All exports are watertight, a single body each, and fit a Bambu P1S.

| Part | Size (mm) | Est. g | Colour | Print orientation |
|---|---|---|---|---|
| v2_torso_frame | 94.5×80×119.5 | 85 | grey (hidden) | back rail face down; tree supports under the deck, yaw sleeves and neck cradle |
| v2_hip_cradle | 63×79×72 | 13 | grey (hidden) | keel down, supports under the T-heads. **PETG, 100% infill** (it is slender) |
| v2_hip_ring | 132×106×16 | 20 | wood brown (under the kilt) | flat, groove up, no supports |
| v2_hip_bracket_L/R | 48×54×75 | 21 each | black | sleeve axis vertical, supports under the webs |
| v2_shoulder_mount_L/R | 32×52×69 | 19 each | wood brown | side plate down, no supports |
| v2_torso_shell_front | 93×98×81 | 34 | wood brown | split face down; tree supports under the shoulder-window tops |
| v2_torso_shell_back | 96×98×58 | 39 | wood brown | split face down; bridge over the switch slot |

- Default print settings: PLA, 0.2 mm layers, 3 walls, 15% gyroid infill.
- Reused from `../stl/`: `twiglet_arm_link_*`, `twiglet_finger_*`, `twiglet_boot_*`.
- In the zip, the reused files are in `stl_reused/`.
- Also reused: the stock ODM leg and hip-yaw parts.
- `v2_shoulder_mount` replaces the old `twiglet_shoulder_mount`.

## Assembly
1. **Frame and hip yaw servos.** Seat both hip-yaw STS3215 in the `torso_frame` sleeves. The back rail carries the battery tray: 2 × 18650 cells in the holder, with the tray floor and side lips.
2. **Hip cradle.** Press the bearings into the cradle's 35 mm seats. Bolt the cradle under the deck using the T-head posts.
3. **Hip brackets.** Fit them on the yaw horns, then fit the stock hip-roll, pitch and leg chain. The legs sit 45 mm either side of the centreline (the stock ODM is much wider).
4. **Electronics.**
   - The BMS and the charger stand upright in front of the back rail. The charger's USB-C port points down, so you reach it by lifting the kilt.
   - The Waveshare bus-servo board and the Pi Zero 2W stack flat on the yaw sleeves (z 87 and 94).
   - The BNO055 IMU stands on the rail's front face.
   - The power switch sits in the slot in the back shell, left of the battery.
   - Neck, arm and head cables pass up through the neck-sheet slots.
5. **Neck and head.** The neck servo cradle is on the frame front, and head A mounts on it unchanged. The head sits 20 mm lower than on the stock build, right on the shoulders like in the photo.
6. **Shoulder mounts.** Each takes 4 × M3 heat-set inserts and bolts to the frame's side rails. The shoulder servo drops into the mount's pocket.
7. **Shell.** The front and back halves join at x = −30 with 4 inner lap tabs and M2.5 screws. Shoulder windows let the arms swing.
8. **Kilt ring.** It clips around the waist. The fabric kilt hooks into the ring's groove through its 12 hook holes.

## Stance and soft limits
**Stance**
- Walking stance: crouch 0.30 with a 0.17 rad forward lean. Without the lean the robot falls forward in the sim.
- Idle stance: straighter (crouch about 0.1) to cut knee load.

**Soft limits** (from `collide_report.json`)

| Joint | Limit |
|---|---|
| Hip roll | ±20 with both legs together; on one leg, inward roll ≤ 9 and the difference between legs ≤ 9° |
| Thigh forward | ≤ 12 (the same hard stop as the stock ODM) |
| Ankle | −65..+47 |
| Hip yaw | ±30 |
| Neck | −5..15 |
| Head pitch | −45..22; ≤ 5 in practice (see head rules) |
| Head roll | ≤ 10 |
| Shoulder | −12..103; if below 0, keep the elbow ≥ 20 |
| Elbow | −20..103; don't combine shoulder > 85 with elbow > 85 |

- Head rules: when |roll| > 5, keep head pitch ≤ 0. When |yaw| > 45, keep head pitch ≤ 0, and ≤ −10 if you are also rolling. Also keep neck − head pitch ≤ 55°: with the neck fully up and the chin tucked, the chin collar hits the shoulder mount. With all these rules the head grid (588 poses) was collision-free.
- With these rules there were no collisions in the rest pose, in 120 walking samples, or in the head and arm sweeps.

## BOM changes vs the stock ODM
**Added**
- **Digital eyes:** 2 × 2.1" round 480×480 displays (e.g. Waveshare), about 30 g each with the PCB, plus an ESP32-S3 or RP2040 driver (about 10 g). They show animated orange-ring and pupil eyes.
  - Extra power: about 0.5–1 W, roughly 0.1 A at 7.4 V. That is about 1–2% of the walking draw (8–10 A peaks).
  - Budgeted in the sim at 70 g in the head.
  - The head's eye sockets will be redesigned separately. **This body release does not change the head.**
- 12 × M3 heat-set inserts (8 for the shoulder mounts plus spares for the frame).
- About 8 × M2.5×8 screws (shell tabs and the hip cradle).
- 2 bearings for the cradle, the same type as the stock hip bearings.

**Removed**
- The printed eye cups, orange rings and eye LEDs.
- The stock chest/pelvis shell parts.
- The SG90 antennas and the cache covers.

**Unchanged:** 20 × STS3215, the Waveshare bus board, Pi Zero 2W, 2 × 18650 with BMS and charger, and the BNO055. They are only relocated.

## Design trade-offs (read before building)
| Aspect | v2 | stock | Notes |
|---|---|---|---|
| Height | 519 mm | 504 (opt1) | head/height 0.33, like Twiglet's chibi look |
| Leg spread | 143 mm | 246 mm | |
| Shoulder width | 213 mm | 117 (opt1, arms in front) | head/shoulder 0.80 vs about 1.16 in the photo |
| Side tipping angle | 13.9° | 29° | |
| Front tipping angle | 4.6° | 13° | |
| Walking speed (open-loop gaits) | 0.05–0.08 m/s | 0.19–0.21 m/s | |
| Standing current | 8 A | 4 A | |

- The shoulders are wider than in the photo because the STS3215 arms are thick and the hip modules sweep a lot of space. Possible fixes are forward-canted arms or micro servos in the arms.
- The main problem is a nose-heavy upper body. Head A is about 480 g with its servos, and the COM sits about 40 mm ahead of the hip-pitch axis. That makes the knees and hips carry 0.7–0.9 N·m standing, above the 0.49 N·m rated torque.
- The RL walking policy must be retrained on `sim/twiglet_v2.xml`.

## Recommendation
Build **option 2** with these changes:
1. Print the head light (2 walls, 5–10% infill). This saves about 100 g and about 0.1 N·m at each joint.
2. Raise the servo P gain (Kp about 20). This halves the sag.
3. Use the straighter idle stance and keep IMU balance on.
4. Plan v2.1 with the hips moved 25 mm forward (this needs the neck servo relocated). Static torque roughly halves.

Use **option 1** (the stock ODM with Twiglet parts) only as a robust fallback. It is not photo-accurate: the legs are wide, the arms sit in front of the trunk, and it weighs 2.73 kg.

## Scripts
| Script | Purpose |
|---|---|
| `design_v2.py` | Parametric parts |
| `view_v2.py` | Dev renders |
| `export_v2.py` | STL export and `build_report.json` |
| `collide_v2.py` | Collision study |
| `render_options.py` | Option renders and the comparison sheet |

Python: `$PYTHON`. pyvista needs `xvfb-run -a -s "-screen 0 1600x1600x24"`.

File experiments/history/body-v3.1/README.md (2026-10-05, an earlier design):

# Twiglet Open Duck: body v3.1 (look pass: arms at the sides, wooden barrel body)

v3.1 keeps everything that set the v3 proportions:
- 454 mm tall without the hat; head 170 mm = 0.374 of height;
- thigh 22 mm shorter, hips 20 mm forward, battery aft;
- STS3215 legs and neck, STS3032 arms, digital-eye head (head-v3).

It changes the look to match the photo: the arms hang at the sides, the torso is a rounded wood barrel, and the gripper is Feetech-style. v3 is untouched in `../body-v3/`. The v3 README is kept here as `README_v3.md` for the measurement method, the v3 design and the servo choice.

## What changed vs v3 (`design_v3.py`, parameters in `build_report.json`)
**Torso: rounded wooden barrel**
- New shape: an asymmetric superellipse plan (n = 4, front half-depth 60, rear 88), lofted smoothly from the waist (z 25) to a rounded top (z 90).
- Width: 95 mm at the lower chest, 92 mm mid, 88 mm under the collar. v3 was a stepped box, 90 mm overall with a 67 mm front block.
- Front face: 80–86 mm across its first 15 mm (v3: 67).
- Closed 2 mm lid; no servos or brackets visible from the front or side.
- Small printed vine + 4 leaves embossed 1 mm on the chest.
- The shell still splits at x = −20 into front and back halves with tabs.

**Arms at the sides**
- The shoulder STS3032 horn sits on a frame boss that ends flush with the barrel side: shoulder axis at x 4, z 74, just under the collar. v3 had it at x 18, z 80 on a boss in front of the narrow torso.
- The whole arm chain and its joint axes are splayed 18° outward.
- Elbow servo flipped: its horn faces inward, so the wood upper-arm plate runs down the inner side.
- Visible sequence, as in the photo: round **black shoulder joint** → wood upper arm → **black elbow joint** → wood forearm block → black gripper.
- Arm lengths: upper 46 mm, forearm 72 mm (v3: 42 / 45).
- The gripper hangs beside the kilt at hem level, with the fingertips about 7 mm below the hem. Rest pose: shoulder 5°, elbow 20°, so the forearm angles slightly forward.

**Gripper**
- Still STS3032-driven.
- The housing is now a boxy 25 × 27 × ~50 mm black body in the style of the Feetech gripper, with a recessed label panel on the outer face. Fixed and moving fingers as before.

**Legs**
- New wood-look snap-on shin covers (C-clip with a slit on the inboard side) between the knee servo and the boot cuff.
- The knee servos stay dark, as in the photo.
- Thigh covers were not added: the kilt hides the thigh down to the knee servo, and a cover there would clash with the hip-pitch servo at thigh-forward angles above 12°.

**Kilt**
- Still fabric. The render stand-in starts at the waist under the barrel and flares to the hem at z −62. It is now drawn opaque.

## Proportions: v3.1 vs photo (`measure/v31_measure.json`)
| | Photo | v3 | v3.1 |
|---|---|---|---|
| Height without hat (mm) | 454 | 454 / 448 stance | 454 / 448 stance (unchanged) |
| Head / height | 0.374 | 0.374 | 0.374 (unchanged) |
| Shoulder width at joint height (mm) | 152 raw | 146 | 153 |
| Head / shoulder (target 1.16) | 1.12 raw / 1.09 corrected | 1.166 | 1.11 |
| Torso width (mm) | about 100–103 | 90 (front block 67) | 95 / 92 / 88 (front face 80–86) |
| Arm span at elbows (mm) | about 178 | – | 189 |
| Span including grippers (mm) | about 274 | 146 | 270 |
| Arm splay | 10–15° | 0° | 18° |

## Printable parts (`stl/`, `build_report.json`)
- 27 v3.1 STLs (`stl/v31_*.stl`). All are watertight single bodies that fit the 256 mm P1S bed, exported in the orientation with the most bed contact.
- Arm parts are exported unsplayed, so they print flat.

New or changed vs v3:
- `torso_shell_front/back`: barrel with vine relief. Use a brim on the front half, which has a small first-layer area on its split face.
- `torso_frame`: tilted shoulder bosses at the barrel side; rails moved back to x −8..16.
- `hip_ring`: barrel outline.
- `shoulder_sleeve_L/R` (black), `upper_arm_L/R` (wood plate + floor tab, M2 to the sleeve bottom and the servo ears).
- `elbow_sleeve_L/R` (black), `forearm_L/R` (wood block + link).
- `gripper_housing_L/R` (boxy black body), `finger_moving_L/R`.
- `shin_cover_L/R` (wood).

Unchanged from v3: thigh sheets and spacer, neck sheets, hip cradle, hip brackets, boot cuff.
Reused: `stl/reused_head_v3/`, stock ODM parts, and the Twiglet boots.

`stl_v3_old/` holds the v3 STLs that were copied into this folder. It is not part of the v3.1 zips; the originals are in `../body-v3/stl`.

## Collision check (`collide_v3.py`, output `collide_report.json`)
See the report for the full list. The follow-up check of the tightened arm rule is in `collide_v31_rule_check.json`.
- **Rest pose:** no non-adjacent clashes with the arms hanging at the sides.
- **Hip roll:** free range −20..13° per leg, the same as v3. The 13° inward limit is boot against boot, and the arms don't limit it.
  - An interim geometry had the gripper touching the hip bracket at 15° outward. The sim soft limit was left at 15° outward as margin; the gaits use ≤ 13°.
  - Both hips rolling together: ±20°.
- **Knee:** −90..90° (v3: 84°). The shin cover is the limiting part.
- **Head:** pitch −40..5° (v3: −34..5°), roll ±6° (v3: ±5°).
- **Gait samples:**
  - both legs: 0 of 120 collide;
  - single leg at stock limits: 20 of 120, the same foot/ankle contacts as v3; the soft limits avoid them.
- **Arms vs torso, kilt, hips and legs:** no contacts found.
  - The arms sit on the torso sides, 41 mm out from centre at the shoulder boss, splayed 18°.
  - In the arm sweep (shoulder −10..110° × elbow −10..110°), every contact is the gripper, fingers or forearm hitting the chin collar or lower head when shoulder + elbow ≳ 110°.
- **Arm soft rule (v3.1):**
  - shoulder −5..84°, elbow ≤ min(110, 105 − shoulder); `collide_v3.py` and `sim/episode.py` both use it;
  - the sweep before tightening found 6 poses inside the earlier rule, elbow ≤ max(70, 125 − shoulder), that touched the collar, which is why it was tightened;
  - with the new rule: 0 of 24 boundary poses collide, and 0 arm contacts in 80 random walking + arm-swinging poses.
  - The sims ran with the earlier rule. Only the head+arm wave gets close to the new boundary (shoulder 80°, elbow 28° vs a cap of 25°), so the results are effectively unchanged.
  - v3's "elbow ≥ 14° when shoulder < 8°" rule is no longer needed.

## Sims (`sim/`, see `sim/compare_v3_v31.md`)
Same harness and tests as v3:
- standing, push recovery and head/arm motion from `run_tests.py`;
- walking: the v3 gaits re-evaluated on the v3.1 model over 20 randomized trials each (`walk_eval.py`; no new search);
- arm heat from `arm_heat.py`.

Only arm load, payload and the head/arm margin moved noticeably; see the table.

Videos:
- `sim/v31_push_recovery_v3.mp4/.gif`
- `sim/v31_walk_v3.mp4/.gif`, `sim/v31_walk_v3_eff.mp4/.gif`
- `sim/v31_head_arms_v3.mp4/.gif`: the frames were stored upside down by the offscreen renderer and were flipped afterwards.

## Renders (`renders/`)
- `compare_photo_v3_v31.png`: photo | v3 front | v3.1 front | v3 side | v3.1 side | v3 3/4 | v3.1 3/4, same scale; photo-angle 3/4 = az 15°, el 17°.
- `overlay_v31_on_photo.png`, `overlay_v3_on_photo_same_camera.png`, `overlay_photo_v3_v31_side_by_side.png`.
- `v31_three_quarter_photo_match.png`, `v31_front.png`, `v31_front_nokilt.png`, `v31_three_quarter_nokilt.png`, `v31_side_nokilt.png`, `v31_back_three_quarter.png`.

## Remaining differences from the photo
- **Head/shoulder** is 1.11 against the 1.16 target (photo 1.12 raw / 1.09 corrected). The shoulder sleeve has to enclose a 27.5 mm STS3032 on its axis, so each arm is about 34 mm thick against about 26 mm in the photo. The barrel is correspondingly slightly narrower than the photo's (88–95 mm vs about 100–103 mm).
- **Arms:** splayed 18° against 10–15° in the photo, needed to clear the hip brackets when the hips roll. Elbow span is 189 mm vs about 178.
- **Side profile:** the torso is deep front to back (148 mm) for the aft battery. The arms sit in the front third of the barrel, because the hip-yaw servos occupy the middle.
- **Colours:** the wood grain is colour only. The vine relief is simple.
- **Upper arm:** there is no wood cover over the wood upper-arm plate, which is visible only from the side and back.
- **Hip roll:** outward roll is limited to 15°.
- **Gripper payload** is lower than v3: about 50 g continuous at the fingertips, arm horizontal.

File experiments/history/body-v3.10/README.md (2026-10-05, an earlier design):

# Twiglet ODM robot, body v3.7

Built from v3.6, which is left unchanged. The user picked "chunkier boots, wood grain, green leaves and chunkier locks". The two new reference photos (measure/ref_front.png, measure/ref_34.png) guided the grain pattern, the leaf placement and the lock shape. The 210 mm head, all mounts, the cone body, the arms and the legs are as in v3.6.

## What to reprint (changed_parts_v36_to_v37.json)
- **Head (twiglet-head-v3.7-stl.zip):** head_upper, head_lower, snout (grain) and fringe (new). Chin collars, eye bezels and display carriers are unchanged.
- **Body:** torso_shell_front/back (grain, leaf sockets, vine without the old embossed lumps), shin_cover_L/R (grain), upper_arm_L/R and forearm_L/R (grain, leaf socket).
- **New parts:** boot_L/R (chunky boots, which replace the body-v2 boot shells), and leaves (green PLA): leaf_L x2 (shoulders), leaf_M x3 (elbows, top of chest), leaf_S x2 (vine).
- **Unchanged (reuse):** all other parts: frame, cradle, hip ring/brackets, thigh parts, boot cuffs, sleeves, grippers, fingers and head_yaw_to_roll.

## Chunky boots (v37_features.boot)
- Wide, flat black blocks with a rounded toe (superellipse plan, fuller at the front), a thick visible sole band (9 mm, stepped 2.1 mm proud) and a rounded top edge.
- Size: 128.6 x 65.6 x 34.5 mm (v3.6 boot shell: 110 x 53 x 24 mm).
- Hollow: 1.5 mm double wall, cavity open underneath, bridged roof. Print sole down with no supports. About 33 g more per boot than the v2 shell.
- Contact footprint is unchanged: the boot bottom sits 1.5 mm above the floor, so only the TPU sole touches (the sim sole box is identical to v3.6).
- Each boot is shifted 2.5 mm outboard so the inner faces stay as far apart as possible (foot-to-foot).

## Wood grain (v37_features.grain_sph / grain_cyl)
- Pattern: vertical plank-like striations with deeper seams about every 21 mm, faint horizontal ring banding (as in the photos), and concentric rings around the eye sockets.
- Parts: head shells, snout, torso cone shell, upper-arm and forearm covers, shin covers.
- Method: a radial map of each part's outer surface is built from surface samples. A grooved skin (surface + 0.15 - depth x pattern) is subtracted in a thin band just outside the surface (manifold boolean), so inner faces and mounts are never touched and the output stays watertight.
- Depth is up to 0.55 mm and is made shallower locally so that no wall drops below 1.25 mm. Measured minimum wall after grain: head_upper 1.40, head_lower 1.40, snout 1.41, torso shell 1.39, shin covers 1.50, upper arm 1.43, forearm 1.41 mm (grain_report_v37.json).

## Leaves (v37_features.leaf_local / place_leaf / socket)
- Flat pointed leaves, 1.8 mm thick, with engraved veins, a stem, and an integral 2.9 mm peg that goes into a 3.3 mm through-socket in the shell or cover. Print veined face down with the peg up (no supports) in green PLA. Add a drop of CA.
- Seven leaves, placed like the photos: one on each shoulder (upper-arm plate, reaching up over the sleeve, tilted out 30 deg), one on each elbow (forearm), and three on the chest vine (the top one at z 80, lowered from 84 to clear the head at -34 deg pitch).
- The vine relief is kept; its four small embossed leaf lumps were removed.

## Chunky fringe (v37_features.fringe, head_v37.py)
- 11 broad, flat, felt-like locks (38-42 mm wide, about 7 mm thick, soft lens section with a slight central ridge, pointed tips) on a crown cap under the hat. The locks curve down over the upper eye rims and flare out at the sides, as in the photos.
- The underside follows the ball (0.3 mm gap). Bezels and snout are cut clear.
- The one-piece fringe is 150 x 226 x 169 mm, which fits the P1S. Pinned split halves are included as an alternative.
- Screen coverage: 4.2 % of each visible screen circle (v3.6: 0 %). Only the top rim is covered, less than in the photos.

## Eyes
- The firmware already has the heart expression shown in the photos (`EYE HEART`, double beat, in head-v3-digital-eyes/firmware/TwigletEyes/TwigletEyes.ino + eye_bitmaps.h; `pi_eyes.py expr("heart")`). Ring eyes are kept.
- The renders show hearts in v37_vs_new_photos.png and v37_three_quarter_hearts.png.
- Sockets are unchanged: the 82.8 mm black bezels already give a dark socket, and deepening them would move the mounts.

## Checks
- All STLs are watertight, one body each, and fit the P1S (41 body parts, 12 head parts).
- Sims: see sim/compare_v36_v37.md. Mass is +94 g. The walk needed no re-tune.
- Collisions (collide_report.json):
  - No clash at rest or with the arms at rest. Gait with both legs and with arms + legs: 0 contacts. Single-leg check: 21 (the same leg-spacer / shin-cover cases as v3.6's 20).
  - Arm sweep: 51 hits, all arm vs head at extreme poses as before; none involve the leaves.
  - New boot limits: inward hip roll is free to 10 deg (v3.6: 13; the gait uses about 9.1), ankle toe-down is free to -54 deg (v3.6: -65; boot vs boot cuff), and knee to 87 deg.
  - Head pitch is free -36..+10 as in v3.6, so the -34 soft limit keeps its margin (the top chest leaf was lowered for this).
- Fringe printing: the one-piece fringe is exported in the least-overhang orientation found by search (about 25 cm2 over 45 deg). The split halves need only about 7 cm2 each, so print those for minimal supports.

## Remaining differences vs the new photos (not in v3.7 scope)
- Torso: the photos show a slimmer torso narrowing to a thin dark neck, with a visible gap under the head exposing the neck mechanism. The v3.6/v3.7 cone and chin collars close that gap.
- Arms and grippers: the photos show thinner wooden arm segments, big black grippers and a black cable looping from each gripper up to the shoulder.
- Shoulder leaves in the photos are larger clusters (2-3 leaves) sitting on top of the shoulder joint. v3.7 has one leaf per shoulder and elbow, which is subtle in renders against the black sleeves.
- The fringe in the photos is slightly more ragged/asymmetric, and the photo locks cover a bit more of the upper eye.
- Eye sockets in the photos look deeper and larger (dark ring around the screen).

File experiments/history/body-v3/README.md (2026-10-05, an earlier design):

# Twiglet Open Duck: body v3 (proportion pass)

Goal: make the robot match the reference photo (`measure/photo.jpg`). The head stays at 170 mm (Head A with the digital eyes from `head-v3-digital-eyes/`), the robot is about 450 mm tall without the hat, and the shoulders are narrow. The legs and neck keep STS3215s with the same kinematics and servo count. The hat and kilt are fabric and are not printed.

## 1. Photo measurements (`measure/`)
- `measure_photo.py` produces `photo_measure.json` and the annotated `photo_measured.png`.
- `model_measure.py` produces `targets.json` (targets and achieved values for v3 and v2).
- The camera looks down: the view elevation is about 17° at the head, 24° at the waist and 38° at the floor. It was estimated from the torso-bottom ellipse. Vertical segments were corrected with a pinhole model (HFOV 60–80°, nominal 70°), scaled so the head is 170 mm. Uncorrected ratios are also in `photo_measure.json`. The photo looks like a render, so treat the figures as ±5–8%.

All segment ratios are divided by the head diameter D.

| Segment | Photo | **v3** (legs straight) | v2 |
|---|---|---|---|
| Head (visible height) | 0.816 | 0.771 | 0.771 |
| Neck / collar | 0.067 | 0.065 | 0.065 |
| Torso above the kilt | 0.30 | 0.312 | 0.659 |
| Kilt | 0.605 | 0.606 | 0.706 |
| Waist to knee | 0.745 | 0.834 | 0.922 |
| Shin (knee to boot top) | 0.309 | 0.239 | 0.496 |
| Boot / foot | 0.435 | 0.452 | 0.195 |

| Overall | Photo | **v3** | v2 |
|---|---|---|---|
| Height without hat (mm) | 454 (range 432–498) | 454 straight / 448 stance | 528 / 519 |
| Head / total height | 0.374 | 0.374 straight / 0.379 stance | 0.328 |
| Head / shoulder width | 1.12 raw, 1.09 corrected; target 1.16 | **1.166** (shoulders 146 mm) | 0.80 (213 mm) |
| Leg spacing (mm) | 113 | 100 | 90 |
| Knee height (mm) | about 126 | 117.5 | – |

Notes on the matches:
- The head reads shorter than in the photo because the photo's head includes the fringe and hair volume.
- The v3 boot includes the printed boot cuff.
- The shin (knee to boot top) cannot be shortened below the stock shin. The knee sits 8 mm lower than the photo's, because the stock hip yaw/roll/pitch stack sets the waist-to-knee length.

## 2. Design changes from v2 (`design_v3.py`, parameters in `build_report.json`)
**Legs and hips**
- Thigh link 22 mm shorter: new `v3_thigh_sheet_a/b` and `v3_thigh_spacer`. The shin is the stock part; the stock knee-to-ankle sheets are reused.
- Hips 20 mm forward under the COM (`DX_P` 20; the v2 sim fix).
- New `v3_hip_cradle`, `v3_hip_ring` and `v3_hip_bracket_L/R`.
- The legs are now 100 mm apart.

**Neck and head**
- Neck 10 mm shorter, with new `v3_neck_sheet_L/R`.
- The head sits 42 mm lower than in v2.
- The digital-eye head (head-v3) is reused unchanged and printed light: 2 walls and 8% gyroid, about 290 g printed.
- Orange eye-ring annuli are modelled on the head.

**Torso**
- Kept slim (90 mm overall, 67 mm front block) but deepened front to back to 146 mm.
- Battery moved 18 mm back and 7 mm lower as a counterweight.
- New `v3_torso_frame`, and a closed two-piece `v3_torso_shell_front/back`. The shell is split at x = −20 with tabs and has a 2 mm top lid.

**Arms**
- Six STS3032 micro bus servos replace the STS3215s. See `servo_choice.md` for real specs, prices and sources.
- New arm parts: `v3_upper_arm_L/R`, `v3_forearm_L/R`, `v3_gripper_housing_L/R`, `v3_finger_moving_L/R`.
- A **6 V buck** (for example Pololu D36V50F6) must feed the arm branch, because the STS3032 maximum is 7.4 V and a full 2S pack is 8.4 V.

**Kilt and boots**
- Kilt hem at 0.605 D (fabric).
- `v3_boot_cuff` is printed and slips over the stock foot.

**Totals:** 2.17 kg (v2 2.42 kg). COM height 233 mm (v2 262 mm).

## 3. Printable parts (`stl/`, `build_report.json`)
- 21 v3 STLs. All are watertight single bodies, fit the 256 mm P1S bed, and are exported in the orientation with the most bed contact. `build_report.json` lists quantity, size, colour, estimated mass and orientation for each.
- `stl/reused_head_v3/` holds copies of the head-v3 parts.
- Reused stock parts: STS3215 leg and neck assemblies, shin (knee-to-ankle) sheets, feet, and electronics.
- Print notes:
  - Suggested settings: PLA at 0.2 mm layers. Use 3+ walls and 15–25% infill for load-bearing parts (frame, hip parts, thigh and neck sheets, arm links).
  - The torso shell and the head parts use 2 walls and 8% gyroid; the sim mass assumes this light head print.
  - Let the slicer add supports where it needs them. Parts are already oriented for the most bed contact, but the frame and the gripper housings have overhangs.
  - Colours are listed per part.

## 4. Renders (`renders/`)
- `compare_photo_v2_v3.png`: photo, v2 and v3 front, and v2 and v3 side, all at the same scale. Red lines mark the photo's proportions.
- `overlay_v3_on_photo.png`: the v3 render overlaid on the photo (az 15°; `_az10` and `_az20` variants included).
- `v3_three_quarter_photo_match.png`, `v3_front.png`, `v3_front_nokilt.png`, `v3_side_nokilt.png`, `v3_back_three_quarter.png`, `v3_three_quarter_noshell.png`.
- `dev_*.png` are development views.

## 5. Collision check (`collide_v3.py`, output `collide_report.json`)
This uses the body-v2 mesh checker. Free joint ranges:

| Joint | Free range | Limit / note |
|---|---|---|
| Hip yaw | −16..8° | Soft limit ±7° |
| Hip roll | +20° outward, 13° inward | |
| Thigh forward | ≤12° | Same as stock |
| Knee | −90..84° | |
| Ankle | −65..47° | |
| Neck pitch | −1..4° | |
| Head pitch | −34..5° | |
| Head roll | ±5° | |
| Head yaw | ±160° | |
| Shoulder | −5..84° | |
| Elbow | −2..124° | |
| Gripper | 0..60° | |

Coupled arm rule: elbow ≤ max(30, 98 − shoulder), and elbow ≥ 14° when the shoulder is below 8°. There is no overhead wave, because the head sits on the shoulders.

Final run, with hip yaw soft-limited to ±7°:
- **Both-legs gait samples (120): 0 collisions.**
- Single-leg random samples: 15 of 120 collide. All of them involve thigh-forward >12° (the stock limit) or ankle >47°, which are outside the soft limits.
- Gait with the arms moving (80 samples): 1 collision. It happens with the shoulder at 0° and the elbow at 14°: the arm hangs straight down and the gripper housing touches the hip bracket when hip roll is about 6°. **Rule: keep the shoulder at ≥8° (the rest pose) while walking.**
- Arm-sweep contacts (81) are grid points outside the coupled rule or the ranges above.

## 6. Simulations (`sim/`, see `sim/README.md`)
The full table, stock vs v2 vs v3, is in `sim/compare_stock_v2_v3.md`, with `sim/plot_compare.png`.

Videos: `sim/push_recovery_v3.mp4/.gif`, `sim/walk_v3.mp4/.gif`, `sim/walk_v3_eff.mp4/.gif`, `sim/head_arms_v3.mp4/.gif`.

## 7. Trade-offs and risks
**Head and arm motion**
- Head motion is restricted: neck pitch −1..4°, head roll ±5°, head pitch −34..5°. The yaw is free.
- No overhead arm wave, limited arm back-swing, and a coupled elbow limit.
- Continuous waving must be capped at about 0.6 Hz. At 0.8 Hz the STS3032 is at 0.99× rated; at 1.5 Hz it is at 1.63×.
- The gripper is weak: about 8.8 N stall and 2.9 N continuous at the fingertip, against about 38 N for the Feetech STS3215 gripper. The photo's STS3215-size gripper modules are not used.

**Appearance**
- The arm column is 37 mm deep against about 26 mm in the photo, but the overall shoulder width matches (head/shoulder 1.166).
- The torso front looks narrower than the photo (67 mm front block against about 103 mm). The fabric kilt and the shell hide most of this.
- The knee is 8 mm lower than the photo's, because of the stock hip stack.

**Mechanics and power**
- Hip yaw is limited to ±7°, which is fine for walking but gives a reduced turn rate.
- A 6 V buck is needed for the STS3032s.
- The STS3032 costs about US$33–47 (€37 at Eckstein) against €24 for the STS3215: about +€77 for six.
- Walking current is higher than v2 (12.3 A average bus current on the max-speed gait) because v3 actually walks at 0.17 m/s.

**Software and model confidence**
- The Open Duck RL policy must be retrained for the new link lengths and mass distribution.
- A 0.08 rad stance offset is still used in the gait, but the robot stands with no pre-lean.
- The armature, heat and current figures are model estimates.
- Photo measurements carry ±5–8% uncertainty.

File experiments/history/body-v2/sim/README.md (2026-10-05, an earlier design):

# Twiglet body v2: MuJoCo simulation

This folder simulates three robots side by side:
- **v2**: the new photo-accurate body (option 2) with head A.
- **stock**: the unmodified ODM humanoid.
- **opt1**: option 1, which is the stock ODM plus the old Twiglet arms, bib and boots, plus head A.

Everything here is **open-loop gaits plus simple PD and IMU feedback, not an RL policy**. Treat the numbers as a relative comparison between designs, not as absolute predictions.

## Reproduce
Python: `$PYTHON` (mujoco 3.14, trimesh, imageio-ffmpeg, matplotlib). Videos need `MUJOCO_GL=glfw xvfb-run -a -s "-screen 0 1600x1600x24"`.
```
python gen_mjcf.py all              # twiglet_{v2,stock,opt1}.xml, mass_report_*.json, meshes/
python run_tests.py v2              # tests a,b,c,e -> results_v2.json (+ gifs); same for stock / opt1
python walk_search.py v2 800        # max-speed gait search -> walk_v2.json, walk_v2_best.npy
python walk_search.py v2 800 --eff  # energy-aware gait search -> walk_v2_eff.json
python walk_video.py v2 [--eff]     # walk_v2[_eff].gif/.mp4 + trace npz
python sensitivity.py               # sensitivity_v2.json (design what-ifs)
python make_plots.py                # plot_*.png
```
Heads-up: `twiglet_v2.xml` was generated before the last small trims to the shell and shoulder mounts, which differ by less than 10 g. Regenerating it will slightly change the results.

## Model
**Masses**
- Masses come from the meshes. Inertia comes from each mesh, scaled to the part's mass.
- STS3215 servo: 55 g. PLA printed parts: 1.24 g/cm³, modelled as a 0.9 mm solid skin plus 15% infill. TPU: 1.21 g/cm³. Steel parts: 7.85 × 0.8.
- Fixed electronics masses (g):

| Cell ×2 | Holder | BMS | Charger | Switch | Bus board | IMU | Misc wiring/screws |
|---|---|---|---|---|---|---|---|
| 47 each | 12 | 8 | 5 | 3 | 12 | 3 | 60 |

- Validation: the stock model comes out at 2.10 kg; the ODM's own MJCF says 2.06 kg.

**Totals**

| | Total mass | Notes |
|---|---|---|
| v2 | 2.42 kg | head assembly 481 g, trunk 746 g, arm ~140 g each, foot 76 g |
| opt1 | 2.73 kg | |
| stock | 2.10 kg | |

**Head A with digital eyes**
- The printed eye cups, rings and LEDs are removed.
- Added in their place: 2 × 30 g for two 2.1" round 480×480 displays with their PCBs, plus 10 g for an ESP32-S3/RP2040 driver.
- Head A's printed parts come to 308 g under the skin rule. If the head is printed with 3 walls and a denser infill it could weigh about 380–400 g. Print it light (2 walls, 5–10% infill); the sensitivity table below shows what each 100 g costs.
- The Pi Zero mesh is counted as PLA (4 g instead of about 11 g), which is a small error.

**Servo model** (`simlib.py`)
- A PWM DC motor: duty u = clip((Kp·e − Kd·ω)/1.91, ±1), torque = 1.91·u − 0.35·ω, clipped to ±1.91 N·m (stall at 7.4 V).
- Kp 12, Kd 0.25, 0.4° backlash deadband. Joints: armature 0.02, damping 0.05, frictionloss 0.05.
- Current estimate: 0.12 A idle + 2.5 A × |τ|/1.91 per servo.
- Rated continuous torque is taken as about 0.49 N·m. This current model is only an estimate.

**Soft limits** (`episode.py`) come from the collision study in `../collide_report.json`.

## Tests
| Test | What it does |
|---|---|
| a | Stand: support margins, tipping angles, static torques, compliance sag, the open-loop COM window |
| b | Push recovery: 0.1 s pulses in 4 directions, with no controller and with IMU balance |
| c | Weight shift: 0.4 Hz sine on hip roll, checking foot unloading and falls |
| d | Walking: random search + CEM gait optimisation, then 20 randomized trials (mass ±10%, friction, servo gain, latency, terrain) |
| e | Head and arm motion while standing |
| f | Bottleneck analysis: torque peak/RMS vs rating (`plot_walk_torque.png`) and a sensitivity study |

## Results
**Standing and push recovery**

| Metric | v2 (crouch 0.30, lean 0.17) | stock (crouch 0.63) | opt1 |
|---|---|---|---|
| Support margin front / back / side (mm) | 21 / 81 / 65 | 48 / 52 / 114 | 26 / – / 112 |
| COM height (mm) | 262 | 205 | 204 |
| Tipping angle side / front | 13.9° / 4.6° | 29.1° / 13.3° | 28.8° / 7.1° |
| Static forward sag from servo compliance | 10.4° | 4.5° | 11.4° |
| Static torque hip pitch / knee / ankle / neck (N·m) | 0.67 / 0.86 / 0.52 / 0.36 | 0.13 / 0.55 / 0.14 / 0.10 | 0.60 / 1.14 / 0.52 / 0.37 |
| Push survived, no controller, F/B/L/R (N·s) | 0.26 / 1.52 / 0.84 / 0.87 | 1.08 / 1.15 / 2.56 / 2.56 | 0.68 / 2.53 / 2.02 / 2.02 |
| Push survived, IMU balance, F/B/L/R (N·s) | 0.96 / 0.98 / 1.22 / 1.24 | 1.20 / 0.98 / 2.79 / 2.79 | 1.66 / 1.78 / 3.26 / 3.28 |
| Standing bus current (estimate) | 8.1 A | 4.1 A | – |

**Weight shift and walking**

| Metric | v2 | stock |
|---|---|---|
| Weight shift | Fully unloads a foot at 0.15–0.20 rad; falls at 0.25 rad and above | Never unloads below 10–17% |
| Walk, max-speed gait | 100% success, 0.079 m/s, ~10 A | 95% success, 0.205 m/s, ~11 A |
| Walk, energy-aware gait | 95% success, 0.050 m/s, 7.7 A | 95% success, 0.194 m/s, 10.5 A |
| Energy-aware peak/RMS torque, hip pitch / knee / ankle (N·m) | 1.43/0.72, 1.27/0.57, 1.45/0.62 | 1.91/1.10, 1.91/0.99, 1.91/1.10 |

- Head and arm test (e): v2 did not fall and kept at least 30 mm of margin.
  - Neck torque: 0.79 N·m peak, 0.27 N·m RMS.
  - The elbow and gripper hit stall during 1.5 Hz ±40° waving. Keep arm waving at or below 0.8 Hz.
- Stability of v2 without the forward lean:
  - The neutral stance falls forward at 0.74 s.
  - The cause is servo compliance plus a nose-heavy COM: the upper body's COM sits about 40 mm ahead of the hip-pitch axis.

**Sensitivity (v2)**

| Change | Static hip / knee torque (N·m) | Forward sag |
|---|---|---|
| Baseline | 0.64 / 0.72 | 9.2° |
| Head −100 g | 0.54 / 0.62 | 7.9° |
| Hips moved 25 mm forward | 0.37 / 0.53 | 6.6° |
| Both of the above | 0.29 / 0.46 | 5.5° |
| Servo Kp 20 | 0.52 / 0.56 | 4.4° |

Moving the arms back has negligible effect.

## Files
| Type | Files |
|---|---|
| Media | `walk_*.gif/.mp4`, `push_recovery_*.gif/.mp4`, `head_arms_*.gif` |
| Plots | `plot_*.png` |
| Raw results | `results_*.json`, `walk_*.json`, `sensitivity_v2.json`, `mass_report_*.json` |

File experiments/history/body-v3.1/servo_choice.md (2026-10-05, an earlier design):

# Arm servo choice for body v3: Feetech STS3032 (C001)

## The problem
v2 used six STS3215s in the arms (45.2 × 24.7 × 35 mm, 55 g each). Two STS3215 cases side by side made the shoulders 213 mm wide, so head/shoulder came out at 0.80 against about 1.16 in the photo. v3 keeps the same 3 DOF per arm (shoulder pitch, elbow, gripper) on the same Feetech TTL bus, but moves them to a micro bus servo.

## Candidates checked (real parts, real sources)

| | **STS3032-C001 (chosen)** | SCS0009 | STS3215-C001 (v2, reference) |
|---|---|---|---|
| Size (mm) | 23 × 12 × 27.5 body (32 mm over the mounting ears; 31.9 to the spline top) | 23.2 × 12.1 × 25.25 | 45.2 × 24.7 × 35 |
| Mass | 20 g (datasheet 20.6 ± 1 g) | 13.2 g | 55 g |
| Stall torque | 4.5 kg·cm = 0.441 N·m @ 6 V (3.5 kg·cm @ 4.8 V) | 2.3 kg·cm = 0.23 N·m @ 6 V | 19.5 kg·cm = 1.91 N·m @ 7.4 V |
| Rated torque | 1.5 kg·cm = 0.147 N·m | 0.7 kg·cm = 0.069 N·m | about 0.49 N·m |
| No-load speed | 0.09 s/60° @ 6 V (111 rpm) | 0.1 s/60° @ 6 V | 0.192 s/60° @ 7.4 V |
| Current (stall / rated / idle) | 1.2 A / 0.4 A / 0.15 A | – | 2.7 A stall |
| Feedback / range | 12-bit magnetic encoder, 360° | 10-bit potentiometer, 300° | 12-bit magnetic, 360° |
| Gears / case / bearings | metal gears, aluminium case, 2 ball bearings | metal gears, plastic case, no bearings | metal gears, plastic case |
| Protocol | **STS TTL (same as the STS3215 legs/neck)** | SCS protocol (different register map) | STS TTL |
| Voltage | 4.8–6 V typical, 4–7.4 V input range | 4–7.4 V | 6–7.4 V |
| Price | US$32.99 BABSCO; €37.20 Eckstein; US$38.68 DrUAV; US$40 AIFITLAB; US$47.63 RobotShop (C036) | US$9 Seeed; €13 Eckstein; US$19.75 Abra | €24.35 Eckstein; US$23.99 OpenELAB |

Sources:
- STS3032 Feetech datasheet: https://akizukidenshi.com/goodsaffix/STS3032%20SPEC.pdf (dimension drawing on page 6)
- STS3032 Feetech product page: https://www.feetechrc.com/6v-45kg-magnetic-code-360-degree-serial-bus-steering-gear.html
- STS3032 retailers: https://shop.babsco.com/feetech-sts3032-4-5kg-compact-smart-servo-c001 , Eckstein, DrUAV, AIFITLAB, RobotShop
- SCS0009: https://www.feetechrc.com/en/6v-23kg-serial-bus-steering-gear_65522 , https://www.seeedstudio.com/Feetech-SCS0009-Servo-p-6535.html
- STS3215: https://eckstein-shop.de/Feetech-STS3215-74V-19kgcm-plastic-case-metal-gear-magnetic-code-dual-shaft-TTL-serial-servo , https://openelab.com/products/feetech-sts3215-c001-servo-7

## Why the STS3032
1. **Same bus and protocol as the rest of the robot.** STS packets, the same SDK and registers, and a 12-bit 360° magnetic encoder, so the arm code stays as it is. The SCS0009 would need the SCS protocol and a 10-bit potentiometer servo on the same line.
2. **Enough torque with margin.** The worst static load (arm held horizontal, shoulder) is 0.046 N·m with the v3 printed arm (MuJoCo gravity torque). That is 31% of the 0.147 N·m rated torque and 10% of stall. The SCS0009 would already be at 64% of its 0.069 N·m rating before lifting anything.
3. **It hits the width target.** Case 12 mm thick, arm column 37 mm deep: shoulder width 146 mm, head/shoulder **1.166** (target 1.16).
4. Metal gears, 2 ball bearings and an aluminium case: it survives falls onto the arms better than the plastic, bearing-less SCS0009.
5. **Mass.** Six STS3032s are 210 g lighter than six STS3215s. That is a large part of why v3 weighs 2.17 kg against 2.42 kg for v2.

## Power
The datasheet gives 4.8–6 V typical and a 7.4 V maximum. The 2S pack is 8.4 V when full, which is above that maximum. **Put a 6 V buck regulator on the arm branch** (for example Pololu D36V50F6, 6 V 5.5 A). Share the data line and ground with the STS3215 bus. Six arm servos draw 0.9 A at idle; three waving hard draw about 2–3 A peak.

## Can it carry the Feetech grippers? What changes
- **The photo's Feetech gripper modules are STS3215-sized, and v3 does not reuse them.** An STS3215 gripper (≈55 g servo + ≈15–20 g brackets) at the wrist would:
  - raise the shoulder static load to about 0.09 N·m (60% of rated);
  - leave only about 40 g of continuous payload;
  - add 25 mm of width at each wrist, which breaks the slim silhouette.
- **v3 uses an STS3032 as the gripper actuator** in a black printed housing (`v3_gripper_housing_*`), with a printed fixed finger and a moving finger on the horn (`v3_finger_moving_*`).
  - Finger length is 50 mm from the horn axis. Tip force is about 8.8 N at stall and 2.9 N continuous. The STS3215 gripper gives about 38 N.
  - That is plenty for light objects (a ball, a card, a small plush) but it is not a strong gripper.
- **Payload, arm horizontal, measured at the fingertips (about 125 mm from the shoulder):**
  - about 80 g continuous (rated torque);
  - about 320 g brief (stall).
  - Lower-arm poses carry much more.
- **The old STS3215 arm links, fingers and v2 shoulder mounts are not reused.** All arm parts are new (see `stl/v3_upper_arm_*`, `v3_forearm_*`, `v3_gripper_housing_*`, `v3_finger_moving_*`).

## Heat (sim, `sim/arm_heat_v3.json`)
Same commanded motion on v2 and v3: right arm forward at about 65° waving ±20° at the shoulder and ±10° at the elbow, left arm swinging 5–55°.

| Wave frequency | Worst RMS / rated | Copper loss per servo | Verdict |
|---|---|---|---|
| 0.5 Hz | 0.74× | 0.28 W | fine for continuous use |
| 0.8 Hz | 0.99× | 0.51 W | at the rated limit: bursts only, not continuous |
| 1.5 Hz | 1.63× | 1.36 W | will overheat. Limit to a few seconds, or cap continuous waving at about 0.6 Hz in software |

STS3215 arms (v2) on the same motion ran at 0.35× / 0.58× / 1.39× rated at 0.5 / 0.8 / 1.5 Hz, so v2 would also overheat at 1.5 Hz. Sustained waving is the one thing the smaller servo does noticeably worse. Copper loss is (τ_rms / Kt)² · R, with Kt 0.343 N·m/A and R 2.8 Ω for the STS3032. The arm armature in the sim (0.004 kg·m²) is an estimate, so treat these as ±30%.

## v3.1 addendum (arms at the sides, longer forearm)
- Arm layout: the shoulder STS3032 horn is now on a tilted boss that sits flush with the barrel side. The arm chain is splayed 18° outward. The elbow servo horn now faces inward, so the wood upper-arm plate runs on the inner side and the outer face at shoulder height is only the round black shoulder sleeve.
- Arm lengths: upper arm 46 mm and forearm 72 mm (v3: 42 / 45). The gripper box now hangs at kilt-hem level, with the fingertips about 7 mm below the hem.
- Arm mass is about 99 g per side (v3: 86 g).
- Load, arm held straight out:
  - static shoulder torque 0.062 N·m = 0.42× rated (v3: 0.046 N·m, 0.31×);
  - fingertip payload about 50 g continuous and about 230 g brief (v3: about 80 / 320 g).
- The gripper is still STS3032-driven, but the housing is now a boxy 25 × 27 × 50 mm black body in the style of the Feetech gripper, with a recessed label panel. Tip force is unchanged, about 8.8 N stall and 2.9 N continuous at 50 mm.
- Arm-wave heat is re-simulated in `sim/arm_heat_v3.json` (same motion as v3). See `sim/compare_v3_v31.md`.

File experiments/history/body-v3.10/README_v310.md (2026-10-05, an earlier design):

# Twiglet v3.10: curved horn snout (only the snout changed vs v3.9)

Replaces v39_head_snout.stl (everything else on the head is unchanged and reused: head_upper, head_lower, fringe, chin collars, bezels, carriers).

- Shape: gently curved horn. The first 10 mm are straight (clean 3 mm blend fillet onto the ball, no ring), then it bends 15.5 deg up/outward. OD flares smoothly from 66 mm at the root to 74 mm at the mouth, with a 3 mm rounded mouth edge and no separate lip step. The bore widens with the flare from 41 mm (0.62 x OD) to 51 mm at the mouth (0.69 x OD, 1.6 mm inner round) and is 46 mm deep, which keeps the head-pitch load at the v3.9 level. Wood-grain rings follow the curved tube.
- Size [82.4, 74.2, 93.9] mm, 203.8 cm3. Fits the P1S. Watertight: True, bodies: 1.
- Print: wood brown PLA (wood-fill optional), mouth face DOWN (flat annulus on the bed, as exported), spigot up, no supports, 0.2 mm (0.16 mm makes the grain pop), 2 walls (0.8 mm), 8 % gyroid. Use these LIGHT settings: the STS3215 head-pitch 2x margin assumes them. That gives about 53 g (53.1 g in the sim; v3.9 snout 52.6 g). At 3 walls / 15 % it would be ~88 g and ~5.6 h, and the margin would drop below 2x.
- Fit: the same keyed spigot + tab as v3.9 into the unchanged head_lower socket. Dry-fit so the tab sits in the key slot and the root lies flush on the ball, then glue (CA or epoxy). The root is 2.5 mm off the socket centre by design (it covers the socket rim fully and clears the right eye bezel).

## Sims v3.9 vs v3.10

| Metric | v3.9 | v3.10 |
|---|---|---|
| Total mass (kg) | 2.423 | 2.424 |
| Stands with no pre-lean | yes | yes |
| COM height (mm) | 241.1 | 241.1 |
| Support margin front / back / side (mm) | 54 / 48 / 70 | 54 / 48 / 70 |
| Tipping angle side / front (deg) | 16.2 / 12.6 | 16.2 / 12.6 |
| Static hip / knee / ankle N·m (x 0.49 rated) | 0.25 (0.51x) / 0.39 (0.80x) / 0.11 | 0.25 (0.51x) / 0.39 (0.80x) / 0.11 |
| Static neck pitch / head pitch N·m standing (x 0.49 rated) | 0.000 (0.00x) / 0.244 (0.50x) | 0.000 (0.00x) / 0.245 (0.50x) |
| Standing bus current (A) | 4.57 | 4.57 |
| Push survived, no controller F/B/L/R (N·s) | 1.17 / 1.08 / 1.52 / 1.55 | 1.17 / 1.08 / 1.52 / 1.55 |
| Push survived, IMU balance F/B/L/R (N·s) | 1.34 / 0.91 / 1.59 / 1.59 | 1.31 / 0.91 / 1.59 / 1.59 |
| Weight shift 0.4 Hz: min foot load at 0.15 / 0.20 rad | 0.05 / 0.00 | 0.05 / 0.00 |
| Walk max-speed: success (20 rand.) / speed / current | 100% / 0.167 m/s / 11.61 A | 100% / 0.169 m/s / 11.82 A |
| Walk energy-aware: success / speed / current | 100% / 0.132 m/s / 10.63 A | 100% / 0.143 m/s / 10.37 A |
| Head+arm test: fell / min margin / neck peak | no / 33.0 mm / n/a (no joint) N·m | no / 33.1 mm / n/a (no joint) N·m |
| Head+arm test peaks: head pitch / yaw / roll (N·m) | 0.724 / 0.771 / 0.363 | 0.725 / 0.771 / 0.361 |
| Arm wave worst RMS x rated 0.5 / 0.8 / 1.5 Hz | 0.76 / 1.01 / 1.66 | 0.76 / 1.01 / 1.66 |
| Arm wave max copper loss per servo W 0.5 / 0.8 / 1.5 Hz | 0.30 / 0.52 / 1.41 | 0.30 / 0.52 / 1.41 |
| Static shoulder gravity torque, straight arm, worst angle (N·m, x 0.147) | 0.066 (0.45x) | 0.066 (0.45x) |
| Fingertip payload continuous / brief (g), arm horizontal | 49 / 228 | 49 / 228 |
| Arm mass per side (g) | 99 | 99 |

Walks: nominal + 20 randomized 10 s trials (walk_eval.py). Arm-heat rows: arm links unchanged since v3.8 (arm_heat_v3.json carried over) (arm_heat_v3.json carried over).

Head nod (collide_head_v310.json): pitch -36..9 deg (11-12 deg at yaw +-45..90), roll +-9, yaw +-160, same as v3.9; no snout contacts. Gaits: both re-refined (walk_refine.py), 100 % on 20 randomized trials.

Renders: renders/snout_closeup_photo_v39_v310.png, renders/snout_profile_v39_v310.png

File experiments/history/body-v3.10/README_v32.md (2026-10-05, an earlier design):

# Twiglet ODM robot: body v3.2 (bigger head, pyramid body)
Built from body v3.1 (`../body-v3.1`, unchanged). The v3.1 notes are kept in `README_v31.md` and the v3 notes in `README_v3.md`.

v3.2 changes, from user feedback on v3.1:
1. the head is larger relative to the body;
2. the body silhouette tapers more (narrow chest, flaring toward the waist and kilt hem);
3. the arms are less splayed, and the kilt line is lower so more of the wooden torso shows.

## What changed
**Head: 190 mm ball (v3.1: 170 mm), scale 1.118**
- *What scales:* the head-v3 printed shells (dome, lower shell, snout, fringe, chin collars, black eye bezels). They scale about the chin / roll-mount line (`HEAD_Q`, model frame (79, 0, 96)).
  - The chin stays at the same height, and the head grows up and out by 16 mm.
  - Height without the hat is 471 mm (v3.1: 454).
- *Eyes:*
  - **Screens:** the 2.1" Waveshare screens (Ø54 visible) keep their physical size. They and their unchanged carriers move outward with the scaled glass centre, so the screen recess goes from 4.6 mm to about 5.1 mm.
  - **Bezels:** the bezel disc scales to Ø75 mm, still 0.394 of the ball diameter (the photo's eye-disc ratio), with a Ø65 aperture. The screen's black non-active border fills the ring between the Ø54 active area and the aperture (black on black).
  - **Eye art:** the orange ring is drawn 1.118× larger in firmware (ring about Ø41 mm), which still fits inside the 54 mm active area. No bigger screen is needed.
  - **At 200 mm:** the aperture would be Ø68, and a 2.8"/Ø71-active round screen would be the next size up if the black ring looked too wide.
- **Why 190 mm:**
  - 180, 190, 200 and 210 mm were checked analytically (`measure/v32_neck_scale.json`); 190 and 200 mm were run in the full sim.
  - 190 mm is the largest size that keeps at least 1.5× margin on the STS3215's rated torque for static neck pitch: 0.317 N·m standing (final run) = 1.55× under 0.49 N·m rated. 200 mm gives 0.335 N·m = 1.46×.
  - Front tipping angle: 11.2° at 190 mm vs 11.0° at 200 mm (v3.1: 13.0°). Knee static: 0.94× rated at 190 mm vs 0.96× at 200 mm.
  - The 200 mm results are kept in `sim/alt_head200/` and `renders/alt_head200/`.
- **Neck margins at 190 mm** (STS3215: 0.49 N·m rated, 1.91 N·m stall):

| Load | Torque | Margin |
|---|---|---|
| Static neck pitch | 0.317 N·m | 1.55× under rated |
| Static head pitch | 0.268 N·m | 1.83× under rated |
| Head+arm motion peak, neck pitch | 0.826 N·m | 2.31× under stall |
| Head+arm motion peak, head pitch | 0.44 N·m | 4.3× under stall |
| Head+arm motion peak, head yaw | 0.756 N·m | |

- **Print light:** 2 walls (0.8 mm), 8 % gyroid, 3 top/bottom layers. The printed head parts come to about 383 g by the export mass estimate (`build_report.json`). The head assembly in the sim is 576 g, 83 g more than v3.1 (493 g); the whole robot is 78 g heavier.

**Pyramid body**
- The torso barrel now tapers from 103 mm wide at the waist to 80 mm under the collar (half-width table `BARREL_B`).

| Height z (mm) | 28 | 45 | 60 | 75 | 86 |
|---|---|---|---|---|---|
| v3.2 width (mm) | 102 | 98 | 92 | 86 | 80 |
| v3.1 width (mm) | 93 | 95 | 92 | 88 | 80 |

- The top can't narrow further: the hip-yaw sleeves of the internal frame reach y ±36.8 up to z 86.
- The kilt stand-in (fabric; render only) is a steeper cone. Half-widths: 53 mm at the top → 56 → 66 → 76 mm at the hem (v3.1: 50.5 → 66). Front-back half-depth goes to 95 mm.

**Arms and kilt line**
- **Splay:** 13° (v3.1: 18°).
  - 11° was tried first, but the gripper then hit the hip bracket at only 11° outward hip roll (the gaits use up to 13°, the sim soft limit is 15°).
  - At 13° the arms clear up to 17° hip roll.
  - The shoulder boss face moves 5 mm out (YS 41 → 46) so the arms clear the wider lower barrel and pass just outside the kilt hem, as in the photo.
- **Kilt line:** 8 mm lower (KILT_TOP 41 → 33). The hip ring is now z 25–33.

## Proportions (`measure/v32_measure.json`)
All three models are measured the same way; photo values use the ball only (head D 195 px = 170 mm).

| | Photo (ball only) | v3.1 | v3.2 |
|---|---|---|---|
| Height without hat (mm) | 454 | 454 | 471 |
| Head / height | 0.374 | 0.374 | **0.404** |
| Shoulder width at joint height (mm) | 152 raw | 153 | 161 |
| Head / shoulder | 1.12 raw / 1.09 corrected (target 1.16) | 1.11 | **1.18** |
| Span including grippers (mm) | about 274 | 276 | 260 |
| Arm splay | 10–15° | 18° | 13° |

The photo head reads bigger than its ball because of the hair and hat volume, so v3.2 intentionally goes above the ball-only photo ratios, as requested. At 200 mm the ratios would be head/height 0.419 and head/shoulder 1.24.

## Printable parts (`stl/`, `build_report.json`)
- 38 STLs (`stl/v32_*.stl`). All are watertight single bodies that fit the 256 mm P1S bed, exported in print orientation.
  - Body parts use the orientation with the most bed contact.
  - Eye bezels and display carriers are printed with their largest flat face down.
- **New or changed vs v3.1:** `torso_shell_front/back` (taper), `hip_ring` (lower, 8 mm tall), `torso_frame` (longer shoulder bosses, 13° splay), and `v32_head_*`.
  - `v32_head_*` are the scaled head shells; the fringe is split into `_a`/`_b` halves because it is 268 mm wide at this scale.
  - They are exported from the watertight head-v3 solids. The shipped head-v3 STLs have a wood-grain surface and are not watertight.
- `head_display_carrier_L/R` are unchanged 1:1 (they hold the screen module).
- `stl_v31_old/` holds the v3.1 STLs copied in with the folder; it is not part of the zips.

**Head interface caveat**
- Scaling the shells uniformly also scales their internal bosses. The interfaces to the unscaled hardware then sit up to about 4–7 mm off their v3 positions:
  - roll-mount deck holes, Pi Zero standoffs, eye-driver board;
  - display-carrier screw bosses: the carriers are placed at the new eye positions, but their M3 bosses in `head_lower` have moved.
- Before printing the head, re-cut these bosses to the hardware patterns, or rebuild the head with `parts_head3` at R = 95.
- The roll-mount deck is 7 mm higher than the roll mount (scaled about the chin line). It needs a 7 mm printed spacer with the stock 4-hole pattern, or the re-cut boss above.
- Everything outside the head is ready to print.

## Collision check (`collide_v3.py`, output `collide_report.json`)
See the report for details. The follow-up check of the final arm rule is in `collide_v32_rule_check.json`.
- **Rest pose:** no non-adjacent clashes, and nothing touches with the arms at rest.
- **Hip roll:** −17..13° per leg; both hips together ±17° (v3.1: −20..13° and ±20°).
  - The outward limit is now the gripper touching the hip bracket at 17°, because of the 13° splay. That still leaves 2° over the 15° outward soft limit.
  - The inward limit is boot against boot, as before.
- **Knee:** −90..90° (shin cover), unchanged. Hip pitch and ankle are unchanged.
- **Head:**
  - neck pitch −1..+3° (v3.1: +4°) and head pitch −41..+3° (v3.1: −40..+5°), limited forward by the bigger chin collar against the torso shell;
  - roll ±6°, unchanged; yaw free.
  - Sim soft limits were updated to +3°.
- **Gait samples:**
  - both legs: 0 of 120;
  - single leg at stock limits: 20 of 120, the same foot/ankle contacts as v3/v3.1; the soft limits avoid them.
- **Arm sweep** (shoulder −10..110° × elbow −10..110°): 61 contacts, all gripper, fingers or forearm against the chin collar or head at high shoulder + elbow. None fall inside the soft rule.
- **Arms + walking legs:** 1 of 80 poses under the v3.1 rule. The hanging right gripper touched the hip bracket at 10.7° outward roll + 7° yaw with the arm straight down (shoulder 2.8°, elbow 13°).
  - Fixed with a minimum-bend rule: elbow ≥ 25 − shoulder, which the rest pose (5° / 20°) already meets.
  - Final soft rule: shoulder −5..84°, 25 − shoulder ≤ elbow ≤ min(110, 105 − shoulder), in both `collide_v3.py` and `sim/episode.py`.
  - Re-check: the failing sample is clear, and 0 arm contacts in 120 random walking + arm poses (outward hip roll up to 15°, yaw ±7°).
- **Arms vs torso barrel and kilt:** no contacts. At rest the gripper passes just outside the kilt hem.

## Sims (`sim/`, full table in `sim/compare_v31_v32.md`)
Same harness as v3.1:
- `run_tests.py v3`: stand, push, weight shift, head+arm;
- `walk_eval.py v3 [--eff]`: 20 randomized trials;
- `arm_heat.py v3`.

Changes:
- Neck and head pitch soft limit forward is now +3° (v3.1: +4/+5°) because of the larger chin collar. The rest of `sim/episode.py` is unchanged.
- **Arm rule:** new minimum bend, elbow ≥ 25 − shoulder (see Collision check).
- The unrefined v3 max-speed gait reached only 95 % success on v3.2. `walk_refine.py` (new: 24 local perturbations × 10 seeds, verified on the standard 20 seeds) brought it to 100 % at 0.160 m/s. The energy-saving gait is unchanged.

Rows that changed vs v3.1:

| Metric | v3.1 | v3.2 |
|---|---|---|
| Total mass (kg) | 2.213 | 2.291 |
| COM height (mm) | 231.1 | 237.3 |
| Support margin front / back / side (mm) | 53 / 49 / 70 | 47 / 55 / 70 |
| Tipping angle side / front (deg) | 16.9 / 13.0 | 16.5 / 11.2 |
| Static hip / knee / ankle N·m (x 0.49 rated) | 0.24 (0.49x) / 0.37 (0.76x) / 0.11 | 0.32 (0.64x) / 0.46 (0.94x) / 0.19 |
| Static neck pitch / head pitch N·m standing (x 0.49 rated) | 0.261 (0.53x) / 0.229 (0.47x) | 0.317 (0.65x) / 0.268 (0.55x) |
| Standing bus current (A) | 4.81 | 5.66 |
| Push survived, no controller F/B/L/R (N·s) | 1.01 / 0.91 / 1.31 / 1.34 | 0.91 / 1.10 / 1.34 / 1.38 |
| Push survived, IMU balance F/B/L/R (N·s) | 1.12 / 0.80 / 1.36 / 1.38 | 1.10 / 0.89 / 1.41 / 1.43 |
| Weight shift 0.4 Hz: min foot load at 0.15 / 0.20 rad | 0.07 / 0.00 | 0.09 / 0.07 |
| Walk max-speed: success (20 rand.) / speed / current | 100% / 0.172 m/s / 12.37 A | 100% / 0.160 m/s / 12.13 A |
| Walk energy-aware: success / speed / current | 100% / 0.137 m/s / 10.87 A | 100% / 0.128 m/s / 11.04 A |
| Head+arm test: fell / min margin / neck peak | no / 29.3 mm / 0.814 N·m | no / 29.9 mm / 0.826 N·m |
| Head+arm test peaks: head pitch / yaw / roll (N·m) | 0.423 / 0.748 / 0.36 | 0.44 / 0.756 / 0.386 |
| Arm wave max copper loss per servo W 0.5 / 0.8 / 1.5 Hz | 0.29 / 0.52 / 1.41 | 0.30 / 0.52 / 1.41 |
| Static shoulder gravity torque, straight arm, worst angle (N·m, x 0.147) | 0.063 (0.43x) | 0.065 (0.44x) |
| Fingertip payload continuous / brief (g), arm horizontal | 51 / 229 | 50 / 228 |
| Arm mass per side (g) | 97 | 98 |

## Remaining visual differences from the photo
- **Head mechanics:** see the caveat above. The head is a uniform scale of head-v3, not a re-engineered one.
- **Head size:** at 190 mm it still reads a bit smaller than the photo's hair-plus-hat mass. 200 mm (in `alt_head200/`) is closer, but only 1.46× neck margin.
- **Torso top:** can't narrow further (internal hip-yaw sleeves), so most of the pyramid effect comes from the flared bottom and the kilt cone.
- **Side profile:** still deeper front-to-back than the photo (frame and battery).
- **Arms:** splay 13°, the top of the requested ~10–15°. They sit in the front third of the torso side.
- **Shoulders:** the black sleeves sit about 5 mm further out than v3.1.
- **Kilt:** a solid cone stand-in; the real fabric kilt will drape and scallop.

## Files
- **Scripts:** `design_v3.py` (parameters `HEAD_S`, `HEAD_Q`, `scale_head()`), `export_v3.py`, `render_v32.py`, `collide_v3.py`, `view_v3.py`.
- **Renders:**
  - `renders/compare_photo_v31_v32.png`: photo, v3.1 and v3.2 front / side / photo-angle 3/4;
  - `renders/overlay_v32_on_photo.png`: overlay, same camera as v3.1;
  - `renders/overlay_photo_v31_v32_side_by_side.png`;
  - `renders/v32_*.png`.
- **Sims:** `sim/compare_v31_v32.md/.json`, `sim/v31_ref/` (v3.1 results), `sim/walk_refine_v32.json`, videos `sim/v32_*.gif/.mp4`.
- **Measurements:** `measure/v32_measure.json`, `measure/v32_neck_scale.json`.

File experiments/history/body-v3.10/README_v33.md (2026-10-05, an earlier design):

# Twiglet body v3.3

Builds on v3.2 (`README_v32.md`). The changes:
1. The head is 180 mm, measured against the photo, with its mounts re-cut to the real hardware.
2. The barrel torso is rounded, with a domed top.
3. A tapered wooden neck column sits on the barrel top.

## 1. Head: 180 mm ball (v3.2: 190)
- **Photo measurements** (`measure/v33_head_size.json`, `renders/head_size_photo_compare.png`):
  - Body proportions put the bare ball at about 150–180 mm (torso ratio ~161, floor-to-head ~165, shoulder ratio ~180).
  - With the same camera, the 180 mm model silhouette matches the photo's hair outline (x 495–795 px vs 485–795). 190 and 200 are visibly too big.
- **Re-cut to the 1:1 hardware** (`head_recut.py`):
  - Outer shells, snout, fringe, collars and bezels are scaled ×1.0588 about the chin line.
  - The deck (roll-mount holes, Pi and board bosses, dome columns) stays 1:1 and is bridged to the bigger wall.
  - The display carriers and 2.1" modules stay 1:1 and move with the bigger eye (about 1–2 mm out, 4.8 mm up). The M3 insert posts are re-made under them.
  - The pod lift-out clearances are re-cut, and the chin collars get 0.3 mm clearance to the deck.
- **Head print pack:** `$WORK/twiglet-head-v3.3-stl.zip` with `print_sheet_head.md` (about 487 g, ~31 h).
- **Neck torque:** static neck pitch is 0.302 N·m in MuJoCo, 1.62× under the 0.49 N·m rating (v3.2: 1.55×).

## 2. Torso: rounded barrel (`design_v3.py`)
- **Shape:** `BARREL_N` 4 → 2.5 (rounded, no flat faces). The rear and front half-depths now vary with height (`BARREL_ABZ`/`BARREL_AFZ`) and dome into the neck. The vine relief is kept.
- **Depth:** stays about 152 mm. The battery holder at x −100 (up to z 80) and the front cradle at x 42 set it. The rear is 2–5 mm deeper at z 65–83 for holder clearance, and the front 1.5 mm deeper at z 55–81 for the neck side-plate at −1° neck pitch.
- **Inside:**
  - battery 7 mm lower (`BAT_DZ` −14);
  - power switch moved inboard, with a left-side access slot;
  - back rail full width to z 70, then ±23 mm;
  - shoulder rails fused to the hip-yaw sleeves (the z 84–88 side ties are removed).

## 3. Neck column
- **Geometry:** `NECK_COL` is a rounded-rectangle tapered tube from z 84 to z 95 (wall 7 → 2.6 mm), with the front of its top bevelled.
  - The bore (x −4.5..38.5, y ±25.5) is the measured swept footprint of the neck mechanism (x −2..33, y ±23) plus clearance.
  - The head is 6 mm higher (`NECK_CUT` 10 → 4). About 5–8 mm of wooden column shows between the dome and the head's black chin collar (photo neck gap ~11.5 mm).
- **Collision sweep:** neck pitch −1..+5°, head pitch −34..+8°, yaw ±150°, roll ±5°.
  - Collision-free across the whole sim soft box as long as combined forward neck + head pitch is ≤ +3°.
  - The full −34° nod is kept.
- **Soft limits** (`sim/episode.py`): neck −1..+3°, head pitch −34..**0°** (v3.2: +3°). Any split with neck + head forward ≤ 3° is also collision-free.
  - The +3° could not be relaxed: past it, the chin collar's rear edge meets the barrel top when combined with roll or yaw.
  - Single-joint free ranges: neck −1..+9°, head −40..+10°, roll ±12°.

## Collision check (`collide_v3.py` → `collide_report.json`)
- **At rest and in gait:** no clashes at rest. Both-legs gait samples: 0 of 120. Arms moving during gait: 0 of 80 (v3.2: 1). Single-leg samples at stock limits: 20 of 120, the same foot/ankle contacts as before, which the soft limits avoid.
- **Arm sweep:** 56 poses collide, but only 2 are inside the arm rule (25 − shoulder ≤ elbow ≤ min(110, 105 − shoulder)). Both are shoulder 110° with elbow −10° (straight arm raised overhead), where the forearm touches the chin collar. v3.2 had 6 such poses, starting from shoulder 100°.

## Sims (`sim/compare_v32_v33.md`)
- **Mass:** 2.256 kg (v3.2: 2.291).
- **Tipping:** front 11.4° (11.2); side 16.6° (16.5).
- **Static loads:** knee 0.91× rated (0.94×); neck 0.302 N·m (0.317).
- **Walk:** 100% at 0.155 m/s max-speed (0.160, v3.2 gait not re-refined); energy-aware 100% at 0.129 m/s (0.128).
- **Head+arm test:** no fall, min support margin 32.6 mm (29.9). **Neck peak is 0.912 N·m (0.826).** That's a dynamic peak. It isn't caused by the new head-pitch limit (0.920 with the old +3°). It is probably the head riding 6 mm higher over the low neck-pitch axis (z 28), together with the re-cut head's mass distribution.

## Files
- `stl/v33_*.stl`: 37 print-oriented parts, all watertight, single body, P1S fit (`build_report.json`). The head parts are copied from `stl_head/`. v3.2 files are in `stl_v32_old/`.
- Renders (`renders/`):
  - `compare_photo_v32_v33.png` (photo | v3.2 | v3.3: front, side, photo angle);
  - `v33_three_quarter_photo_match.png`, `v33_front.png`, `v33_three_quarter_nokilt.png`, `v33_side_nokilt.png`;
  - `overlay_v33_on_photo.png`, `overlay_photo_v32_v33_side_by_side.png`, `head_size_photo_compare.png`.
- Collision results: `collide_report.json`.
- Scripts: `export_v3.py`, `export_head_v33.py`, `render_v33.py`, `head_size_compare.py`, `head_recut.py`, `sim/compare_v33.py`.

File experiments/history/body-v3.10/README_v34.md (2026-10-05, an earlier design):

# Twiglet body v3.4: head moved back, cone torso

Built from v3.3 (body-v3.3/ is unchanged). Changes answer the feedback "head not over the middle, body should be one cone".

## What changed
- **Neck stack 1.5 mm rearward** (DXN 18 -> 16.5; NECK_COL and HEAD_Q follow). This is the hard limit: the trunk neck-pitch servo sits right in front of
  the hip-roll horn plates of both hip brackets (x -2..3). At 7 deg hip yaw the plates swing ~1 mm forward and ~4 mm inboard. A 7 mm and a 3 mm shift were
  both built and failed the collision check (rest clash / gait clash). The neck-servo cradle rear wall and floor are now only a |y|<4 centre strip, and the
  hip-bracket front web is trimmed inboard (y>=26).
- **Cone torso shell** (torso_env_v34.py -> torso_env_v34.json): station rings = convex hull of the internals (incl. +-7 deg hip-yaw sweep, neck parts)
  + 2.6 mm, 45 deg chamfer, flared toward the waist, domed into the neck column. Shell section w x d: z25 109 x 128 -> z60 89 x 114 -> z86.5 77 x 99 ->
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

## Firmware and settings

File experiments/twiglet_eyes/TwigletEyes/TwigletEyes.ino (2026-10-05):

/*  TwigletEyes - pixel-art eyes for Twiglet (Open Duck Mini v2 head A v3)
    Board : Waveshare ESP32-S3-Touch-LCD-2.1 (flat panel, 480x480 ST7701 RGB), one board per eye, same firmware on both.
    Arduino IDE: board "ESP32S3 Dev Module" (esp32 core >= 3.0), PSRAM "OPI PSRAM", Flash 16MB, USB CDC On Boot "Disabled"
                 (so Serial = UART0 = GPIO43/44 = the 12-pin header TXD/RXD and the "UART" USB-C port).
    Link   : Pi Zero 2W /dev/serial0 115200 8N1. Pi TX -> RXD (GPIO44) of BOTH boards; L board TXD (GPIO43) -> Pi RX. Common GND.
    Protocol (one line per command, '\n' terminated, case-insensitive; optional "L:" / "R:" prefix = only that eye):
      EYE ring|heart|happy|angry|wide|blink|off|test    LOOK x y   (x,y -1..1; +x = toward the robot's own left, +y = up)
      BLINK          AUTOBLINK 0|1     BRIGHT 0..100     COLOR rrggbb
      SIDE L|R       ROT 0..3          MIRROR 0|1        CENTER x y      SAVE     INFO     PING
    Replies ("OK ...", "ERR ...") are only sent by the eye whose SIDE is L (its TX is the only one wired back), unless ECHO 1. */
#include <Arduino.h>
#include <Preferences.h>
#include <WiFi.h>
#include "st7701_panel.h"
#include "eye_bitmaps.h"
#include "eye_geometry.h"

enum Expr { E_RING, E_HEART, E_HAPPY, E_ANGRY, E_WIDE, E_OFF, E_TEST };
struct Cfg { char side; int cx, cy, rot, mirror, bright; uint16_t color; bool autoblink, echo; } cfg;
static Expr expr = E_RING;
static float lookX = 0, lookY = 0;                 // -1..1
static uint32_t blinkStart = 0; static bool blinking = false; static uint32_t nextBlink = 3000;
static uint32_t exprStart = 0;
static bool dirty = true;
Preferences prefs;

static uint16_t rgb565(uint32_t rgb) { return ((rgb >> 8) & 0xF800) | ((rgb >> 5) & 0x07E0) | ((rgb >> 3) & 0x001F); }
static void loadCfg() {
  prefs.begin("twigleteyes", true);
  cfg.side = (char)prefs.getUChar("side", DEFAULT_SIDE);
  bool L = cfg.side == 'L';
  cfg.cx = prefs.getInt("cx", L ? GEO_L_CX : GEO_R_CX); cfg.cy = prefs.getInt("cy", L ? GEO_L_CY : GEO_R_CY);
  cfg.rot = prefs.getInt("rot", L ? GEO_L_ROT : GEO_R_ROT); cfg.mirror = prefs.getInt("mir", 0);
  cfg.bright = prefs.getInt("bri", 80); cfg.color = prefs.getUShort("col", rgb565(0xFF7A00));
  cfg.autoblink = prefs.getBool("ab", true); cfg.echo = prefs.getBool("echo", false);
  prefs.end();
}
static void saveCfg() {
  prefs.begin("twigleteyes", false);
  prefs.putUChar("side", cfg.side); prefs.putInt("cx", cfg.cx); prefs.putInt("cy", cfg.cy); prefs.putInt("rot", cfg.rot); prefs.putInt("mir", cfg.mirror);
  prefs.putInt("bri", cfg.bright); prefs.putUShort("col", cfg.color); prefs.putBool("ab", cfg.autoblink); prefs.putBool("echo", cfg.echo);
  prefs.end();
}
static void reply(const String &s) { if (cfg.side == 'L' || cfg.echo) Serial.println(s); }

// ---------------- drawing ----------------
static uint16_t *fb;
static inline void fillRect(int x0, int y0, int w, int h, uint16_t c) {
  int x1 = x0 + w, y1 = y0 + h; if (x0 < 0) x0 = 0; if (y0 < 0) y0 = 0; if (x1 > PANEL_W) x1 = PANEL_W; if (y1 > PANEL_H) y1 = PANEL_H;
  for (int y = y0; y < y1; y++) { uint16_t *p = fb + y * PANEL_W + x0; for (int x = x0; x < x1; x++) *p++ = c; }
}
// art-frame point (u right, v up; pixels from the aperture centre) -> panel pixel
static void artToPanel(int u, int v, int &x, int &y) {
  if (cfg.mirror) u = -u;
  int px, py;                                       // un-rotated: art right = +x, art up = -y
  switch (cfg.rot & 3) { case 0: px = u; py = -v; break; case 1: px = v; py = u; break; case 2: px = -u; py = v; break; default: px = -v; py = -u; break; }
  x = cfg.cx + px; y = cfg.cy + py;
}
// one LED "dot": EYE_DOT x EYE_DOT rounded square centred on art cell (i,j) shifted by (di,dj) cells
static void dot(int i, int j, uint16_t c) {
  int u = (int)((j - (EYE_N - 1) / 2.0f) * EYE_CELL), v = (int)(-(i - (EYE_N - 1) / 2.0f) * EYE_CELL);
  int x, y; artToPanel(u, v, x, y);
  int h = EYE_DOT / 2;
  fillRect(x - h + 1, y - h, EYE_DOT - 2, EYE_DOT, c); fillRect(x - h, y - h + 1, EYE_DOT, EYE_DOT - 2, c);   // 1 px cut corners
}
static inline bool bmpGet(const uint8_t (*b)[EYE_N / 8], int i, int j) {
  if (i < 0 || j < 0 || i >= EYE_N || j >= EYE_N) return false; return b[i][j >> 3] & (0x80 >> (j & 7));
}
// lids: top/bottom limits in cells from the centre (rows with |row centre| outside are hidden); closed -> 3-row line
static void drawBitmap(const uint8_t (*b)[EYE_N / 8], int di, int dj, float lidTop, float lidBot, bool closed) {
  const float c0 = (EYE_N - 1) / 2.0f;
  for (int i = 0; i < EYE_N; i++) {
    float yc = -(i - c0);
    for (int j = 0; j < EYE_N; j++) {
      float xc = j - c0;
      if (xc * xc + yc * yc > EYE_VIS_R * EYE_VIS_R) continue;
      bool on;
      if (closed) on = fabsf(yc) <= 1.5f && fabsf(xc) <= EYE_R_OUT - 0.5f;
      else on = bmpGet(b, i - di, j - dj) && yc <= lidTop && yc >= lidBot;
      if (on) dot(i, j, cfg.color);
    }
  }
}
static void drawTest() {
  fillRect(0, 0, 40, 40, rgb565(0xFF0000));                           // native (0,0) corner: red square
  fillRect(PANEL_W / 2 - 1, 0, 2, PANEL_H, rgb565(0x303030)); fillRect(0, PANEL_H / 2 - 1, PANEL_W, 2, rgb565(0x303030));
  // art-frame arrow pointing UP (world up) + a dot on the viewer's RIGHT, centred on the configured aperture centre
  for (int k = 0; k < 14; k++) { dot(26 - k, 19, cfg.color); dot(26 - k, 20, cfg.color); }
  for (int k = 0; k < 5; k++) { dot(12 + k, 19 - k, cfg.color); dot(12 + k, 20 + k, cfg.color); }
  dot(19, 33, rgb565(0x00FF00)); dot(20, 33, rgb565(0x00FF00));
  // aperture outline (56 mm = ~250 px radius) in grey
  for (int a = 0; a < 360; a += 2) { int x, y; artToPanel((int)(249 * cosf(a * DEG_TO_RAD)), (int)(249 * sinf(a * DEG_TO_RAD)), x, y); fillRect(x - 1, y - 1, 3, 3, rgb565(0x606060)); }
}
static void render() {
  fb = panel_backbuffer();
  memset(fb, 0, PANEL_W * PANEL_H * 2);
  uint32_t t = millis();
  // blink: 7 phases x 55 ms (open, 1/3, 2/3, closed, 2/3, 1/3, open)
  float lidTop = 99, lidBot = -99; bool closed = false;
  if (blinking) {
    int ph = (t - blinkStart) / 55;
    static const float TOP[7] = {99, 8, 3, 0, 3, 8, 99}, BOT[7] = {-99, -11, -6, 0, -6, -11, -99};
    if (ph >= 7) blinking = false; else { lidTop = TOP[ph]; lidBot = BOT[ph]; closed = ph == 3; }
  }
  int dj = (int)roundf(lookX * 4.0f * (cfg.mirror ? 1 : 1)), di = (int)roundf(-lookY * 3.5f);
  // +LOOK x = toward the robot's own left = the viewer's right = +art x (same for both eyes)
  switch (expr) {
    case E_RING: drawBitmap(BMP_RING, di, dj, lidTop, lidBot, closed); break;
    case E_WIDE: drawBitmap(BMP_WIDE, di, dj, lidTop, lidBot, closed); break;
    case E_HAPPY: drawBitmap(BMP_HAPPY, 0, 0, 99, -99, false); break;
    case E_ANGRY: drawBitmap(cfg.side == 'L' ? BMP_ANGRY_L : BMP_ANGRY_R, di, dj, 99, -99, false); break;
    case E_HEART: { uint32_t b = (t - exprStart) % 900; drawBitmap((b < 180 || (b > 330 && b < 480)) ? BMP_HEART : BMP_HEART_SMALL, 0, 0, 99, -99, false); break; }  // double beat
    case E_TEST: drawTest(); break;
    case E_OFF: break;
  }
  panel_present();
}

// ---------------- commands ----------------
static void startBlink() { blinking = true; blinkStart = millis(); dirty = true; }
static void handle(String line) {
  line.trim(); if (!line.length()) return;
  String up = line; up.toUpperCase();
  if (up.length() > 2 && up[1] == ':' && (up[0] == 'L' || up[0] == 'R')) { if (up[0] != cfg.side) return; up = up.substring(2); up.trim(); }
  int sp = up.indexOf(' '); String cmd = sp < 0 ? up : up.substring(0, sp); String arg = sp < 0 ? "" : up.substring(sp + 1); arg.trim();
  if (cmd == "EYE") {
    if (arg == "BLINK") { startBlink(); }
    else {
      Expr e;
      if (arg == "RING" || arg == "DEFAULT") e = E_RING; else if (arg == "HEART" || arg == "HEARTS") e = E_HEART; else if (arg == "HAPPY") e = E_HAPPY;
      else if (arg == "ANGRY") e = E_ANGRY; else if (arg == "WIDE") e = E_WIDE; else if (arg == "OFF") e = E_OFF; else if (arg == "TEST") e = E_TEST;
      else { reply("ERR unknown eye " + arg); return; }
      expr = e; exprStart = millis(); if (e == E_OFF) panel_backlight(0); else panel_backlight(cfg.bright);
    }
  } else if (cmd == "BLINK") startBlink();
  else if (cmd == "LOOK") { float x = 0, y = 0; sscanf(arg.c_str(), "%f %f", &x, &y); lookX = constrain(x, -1.0f, 1.0f); lookY = constrain(y, -1.0f, 1.0f); }
  else if (cmd == "AUTOBLINK") cfg.autoblink = arg.toInt() != 0;
  else if (cmd == "BRIGHT") { cfg.bright = constrain(arg.toInt(), 0, 100); panel_backlight(cfg.bright); }
  else if (cmd == "COLOR") cfg.color = rgb565(strtoul(arg.c_str(), nullptr, 16));
  else if (cmd == "SIDE") { if (arg == "L" || arg == "R") cfg.side = arg[0]; }
  else if (cmd == "ROT") cfg.rot = arg.toInt() & 3;
  else if (cmd == "MIRROR") cfg.mirror = arg.toInt() != 0;
  else if (cmd == "CENTER") { sscanf(arg.c_str(), "%d %d", &cfg.cx, &cfg.cy); }
  else if (cmd == "ECHO") cfg.echo = arg.toInt() != 0;
  else if (cmd == "SAVE") saveCfg();
  else if (cmd == "PING") { reply(String("PONG ") + cfg.side); return; }
  else if (cmd == "INFO") { reply(String("INFO side=") + cfg.side + " cx=" + cfg.cx + " cy=" + cfg.cy + " rot=" + cfg.rot + " mirror=" + cfg.mirror + " bright=" + cfg.bright + " expr=" + (int)expr); return; }
  else { reply("ERR unknown " + cmd); return; }
  dirty = true; reply("OK " + up);
}

void setup() {
  Serial.begin(115200);
  WiFi.mode(WIFI_OFF); btStop();
  loadCfg();
  if (!panel_begin()) { Serial.println("ERR panel init failed (PSRAM enabled?)"); }
  panel_backlight(cfg.bright);
  exprStart = millis(); nextBlink = millis() + 2500 + (cfg.side == 'R' ? 0 : 0);
  reply(String("READY TwigletEyes side=") + cfg.side);
}
void loop() {
  static String buf;
  while (Serial.available()) { char ch = Serial.read(); if (ch == '\n' || ch == '\r') { handle(buf); buf = ""; } else if (buf.length() < 96) buf += ch; }
  uint32_t t = millis();
  // auto-blink: both boards get the same random seed schedule only if commanded; Pi can send "BLINK" to sync both eyes
  if (cfg.autoblink && !blinking && (expr == E_RING || expr == E_WIDE) && (int32_t)(t - nextBlink) >= 0) { startBlink(); nextBlink = t + 2500 + (esp_random() % 4000); }
  bool animating = blinking || expr == E_HEART;
  static uint32_t lastFrame = 0;
  if ((dirty || animating) && t - lastFrame >= 16) { lastFrame = t; dirty = false; render(); }
  else delay(1);
}

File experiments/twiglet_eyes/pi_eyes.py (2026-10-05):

"""Tiny Pi-side driver for the two TwigletEyes boards (Pi Zero 2W UART /dev/serial0, 115200).
Enable the UART: raspi-config -> Interface -> Serial: login shell NO, hardware YES.  pip install pyserial"""
import serial, time
class Eyes:
    def __init__(self, port="/dev/serial0", baud=115200):
        self.s = serial.Serial(port, baud, timeout=0.2)
    def cmd(self, line, side=None):
        self.s.write(((f"{side}:" if side else "") + line + "\n").encode())
        return self.s.readline().decode(errors="ignore").strip()     # reply comes from the L board only
    def expr(self, name): return self.cmd(f"EYE {name}")             # ring heart happy angry wide blink off test
    def look(self, x, y): return self.cmd(f"LOOK {x:.2f} {y:.2f}")   # -1..1, +x = robot's own left, +y = up
    def blink(self): return self.cmd("BLINK")
if __name__ == "__main__":
    e = Eyes(); print(e.cmd("PING"))
    for n in ("ring", "happy", "angry", "heart", "wide", "ring"):
        print(n, e.expr(n)); time.sleep(1.5)
    for x in (-1, 0, 1, 0): e.look(x, 0); time.sleep(0.6)
    e.blink()

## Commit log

2026-10-05 Initial public release: Twiglet, an Open Duck Mini v2 morph with wooden head, wig, kilt and arms
    Apache-2.0. Built on Open Duck Mini v2 (apirrone) under Apache-2.0; see NOTICE.
    [BOM.csv, FINAL_WIG.stl, FINAL_WIG_model_frame.stl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]
2026-11-08 Record the timed heading-handoff qualification.
    The reset integrator now stays on until the heading command is moving, which is a separate law from the frozen cfg_b sample. On new seeds the +20° and +45° commands clear a Wilson 95% lower bound of 99.5%. Negative turns, the 90° commands, and the 6°/s half-turns do not.
2026-11-08 Record the onset right-stance flip qualification.
    For the first 0.40 s of a slew, a loaded right hip gets the opposite yaw sign. On new seeds both 20° arcs and the +45° turn clear a Wilson 95% lower bound of 99.5%. The 90° commands and the −45° turn still miss, on shorts and pitch falls.
2026-11-08 Record the pitch-yaw limit on the qualified manoeuvre law.
    Yielding hip yaw during the pitch catch does not stop the falls and makes the 90 degree shorts worse, so the controller hash is unchanged. A declared 8 deg/s 90 degree command tracks the recorded shorts, and the early pitch fall and a 16 degree wrong-way peak remain.
2026-11-09 Record the step-guard restart trial.
    A longer touchdown during a turn now shortens the next swing, and the later restart cycle uses a 0.04 rad yaw trim. The preregistered restart block is 999/1000, Wilson lower bound 99.44%, so it does not clear 99.5%. The cfg_d turn counts stay on their own hash.
2026-11-09 Qualify the restart after resetting the later-cycle yaw integral.
    The first walk's integral was still pushing the second start the wrong way. On new seeds the restart is 1000/1000, Wilson lower bound 99.62%. The cfg_e 999/1000 stays on its own hash, and seed 270260 is recorded as a straight-walk fall outside the earlier paired set.
2026-11-09 Record the segmented 4 deg/s route screen without a new qualification.
    A continuous chain of 20 deg arcs with declared holds finishes several recorded misses and still fails a known fall and a 19 deg wrong-way peak. The controller hash is unchanged.
2026-11-09 Record the stance hip-roll slalom trial.
    Knee and ankle are already near the stall rail in a normal step, so the pitch support uses hip roll. The preregistered slalom is 999/1000, Wilson lower bound 99.44%. The cfg_f restart thousand stays on its own hash.
2026-11-09 Record the onset-hold qualifications and a torque what-if.
    A negative slew waits for the right foot, and hip-roll support waits until pitch is past -8 deg. On this law, -90 deg at 8 deg/s and the slalom are each 1000/1000. A separate model with 2.9 N·m sagittal motors is labelled hypothetical and is not the canonical XML.
2026-11-09 Replace the README hero with the v6.11 hair render.
    The front and back images are the supplied rest-pose renders. Captions name hair v6.11 (v6b0). The results table and the assembly-step images stay.
